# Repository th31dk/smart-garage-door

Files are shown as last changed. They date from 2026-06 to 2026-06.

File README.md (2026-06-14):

<h1 align="center">
    ESPGarageLink
</h1>
<h4 align="center">
    Inexpensive Garage Door Opener Link for Home Assistant
</h4>

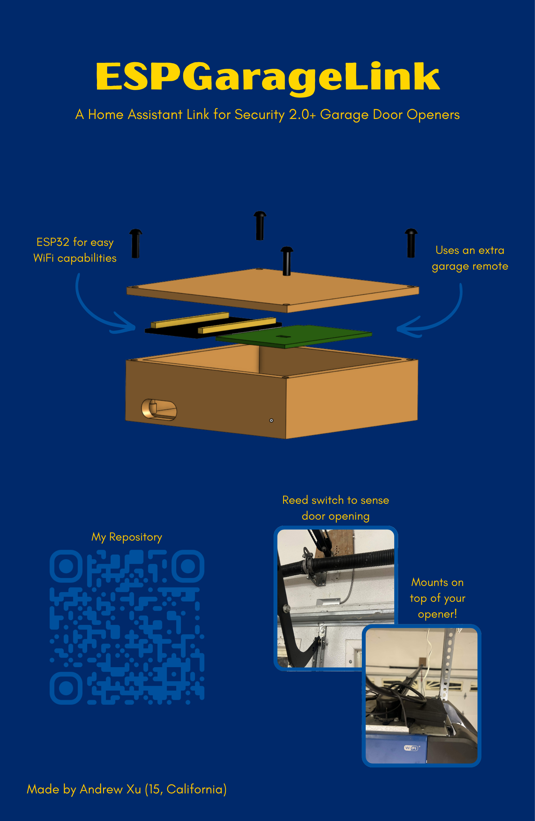
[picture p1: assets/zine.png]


<h2 align="center">
About This Project
</h2>
Throughout my life, I would often forget if I closed garage door was closed before heading out of the house. I would have to turn around for the slight chance that it was left open. I built this project to counter this. It uses ESPHome to easily integrate with Home Assistant.

<h2 align="center">
BOM
</h2>

|Part Number|Part Name |Quantity|Sourcing Link |Cost  |Notes |
|---|---|---|---|---|---|
|1 |ESP32 |1 |https://www.aliexpress.us/item/3256806060462387.html|$5.02 | |
|2 |Garage Door Remote|1 |https://a.co/d/0b3jvMXJ |$6.99 |has to be compatible with your garage opener model|
|3 |22awg dual wire |100ft |https://a.co/d/04LgN8tN |$15.99| |
|4 |Reed Switch |1 |https://a.co/d/087Lrm4S |$9.88 | |
|5 |M3x10 BHCS |4 |https://www.aliexpress.us/item/2251832624537980.html|$2.02 | |
|6 |1K Resistor |1 |https://www.aliexpress.us/item/3256802303553096.html|$0.90 | |
|7 |2N2222A Transistor|1 |https://www.aliexpress.us/item/3256808419495041.html|$1.91 | |

<h2 align="center">
Assembly
</h2>

|Case Assembly |Wiring Diagram |
|---|---|
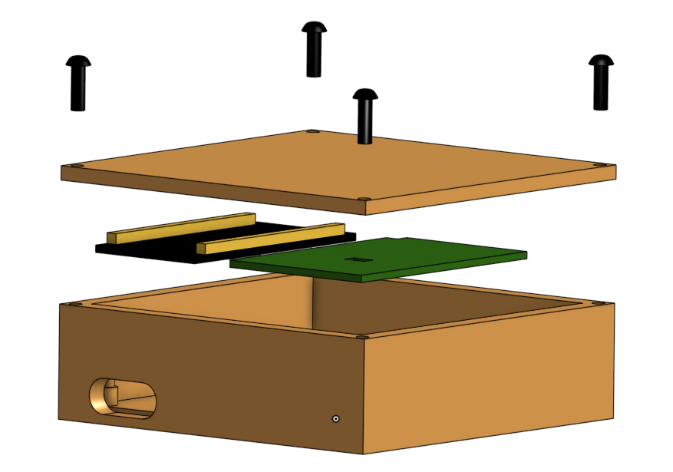
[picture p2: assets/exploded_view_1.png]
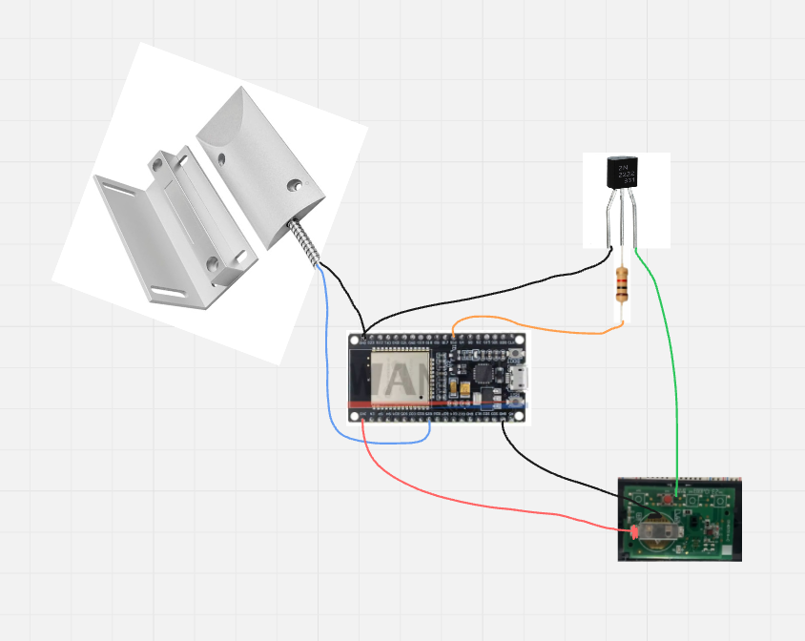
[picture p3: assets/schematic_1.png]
|||

1. Solder the wires to the correct spots on the Garage Remote PCB
2. Place the ESP32 and PCB inside the case.
4. Measure out the length of wire you need to connect the sensor to the ESP32 and cut it. (**MAKE SURE TO ADD SOME EXTRA LENGTH**)
5. String it through the circular hole in the case and connect it to the ESP32
6. Solder the rest of the connections
7. Screw the top case on
8. Flash your ESP32 with ESPHome
9. Link the ESP32 to ESPHome and upload the code to it. 
10. Install the parts in your garage

Source files can be found [here](https://cad.onshape.com/documents/4649b205c89024a5f1492af2/w/5978872a114fc81fb7337ada/e/29e5e7a7f49cdcf4b48956bb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)

<h2 align="center">
Credits
</h2>

Thank you to [Hack Club](https://hackclub.com/) for supporting my projects! They're truly an amazing organization.

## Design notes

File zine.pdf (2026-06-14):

# ESPGarageLink

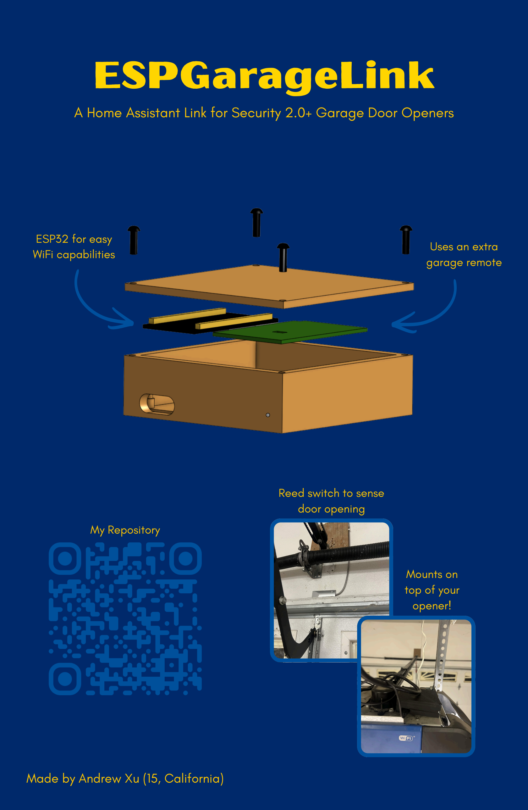
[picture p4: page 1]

### A Home Assistant Link for Security 2.0+ Garage Door Openers

Made by Andrew Xu (15, California)

ESP32 for easy
WiFi capabilities

Uses an extra
garage remote

Reed switch to sense
door opening

Mounts on
top of your
opener!

My Repository

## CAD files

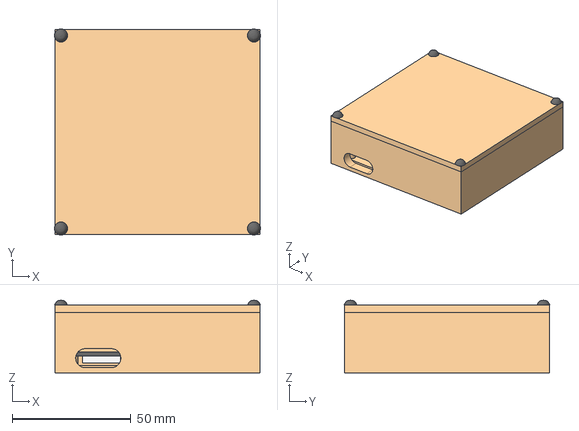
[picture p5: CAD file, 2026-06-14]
3D Models/Project Assembly.step
86.7 x 86.7 x 30.6 mm

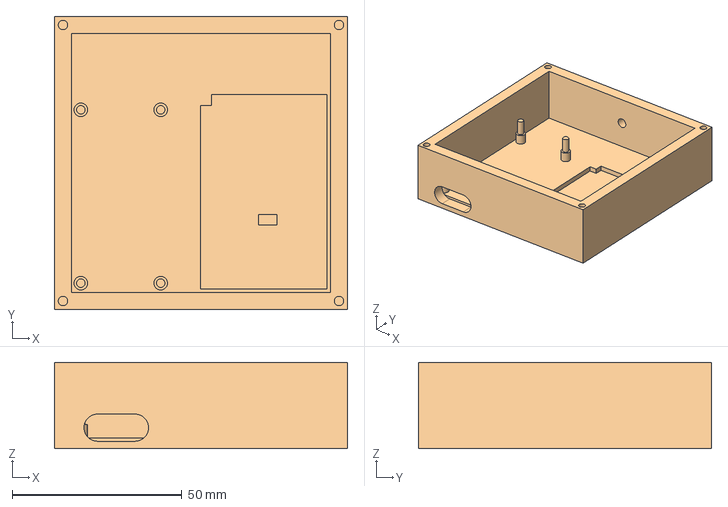
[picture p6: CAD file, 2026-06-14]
3D Models/Case Base.step
86.2 x 86.2 x 25.4 mm

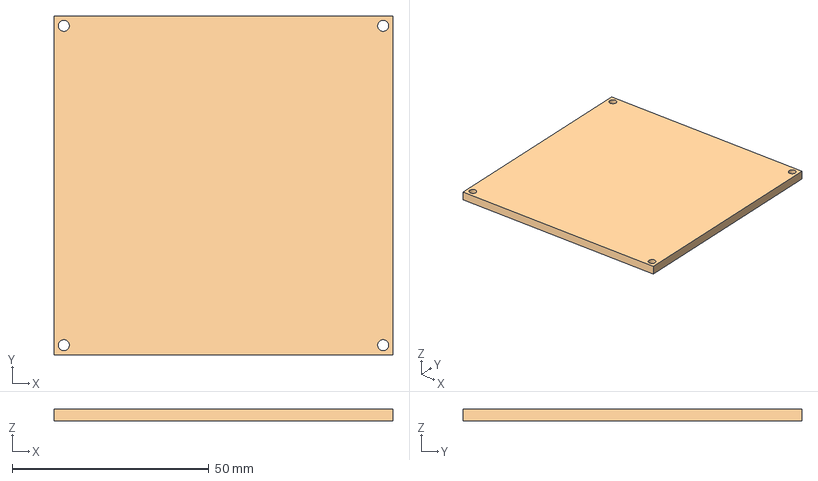
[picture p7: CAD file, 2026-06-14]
3D Models/Case Top.step
86.2 x 86.2 x 3.17 mm

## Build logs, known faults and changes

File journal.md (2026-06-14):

# Journal Information
Hi, my name is Andrew and welcome to my project journal! I will be documenting my entire journey right here. 

## Engineering Design Process
Throughout this project, I will be using the engineering design process to iterate on my designs. 

1. Identify the problem
2. Brainstorm Solutions
3. Implement The Best One
4. Build The Model
5. Test For Problems

# Journal Entries
## June 12th, 2026 - Friday
So, for the past year, I've wanted to smartify my house, but most products seemed overpriced and didn't fit my needs. I also didn't have an excuse to spend that much money on smart home products. Well, I realized I was getting to places late because my parents would forget whether or not they'd closed the garage door, and we'd have to go back home when we were already a mile away.

After some research, I've found that all the solutions didn't quite fit my constraints. The simplest solution I found was using myQ. My current garage door even has myQ built in. Now, don't get me wrong, myQ seems very simple to set up, except for the fact that they stopped supporting smart ecosystem software like Home Assistant and HomeKit. From that problem, RATDGO and Open Garage were born. They both essentially hack the garage door opener into letting Home Assistant use it. They're almost perfect, except it's kind of expensive to buy them. 

Now for my idea. I want to make a cheaper version that has all the features I need.

Here's what I want:

- Ability to open and close from my phone
- Ability to see if the door is open or closed

I know that doesn't seem like a lot of features, but we can always add more in v2.

Well the first feature I want to have is seeing if it's open or not. For this, I think we should take some inspiration from security systems. To secure the garage door, companies usually use a reed switch. A reed switch is a switch that switches when a magnet is near. My dad actually has a spare one, so I'll just use that one. 

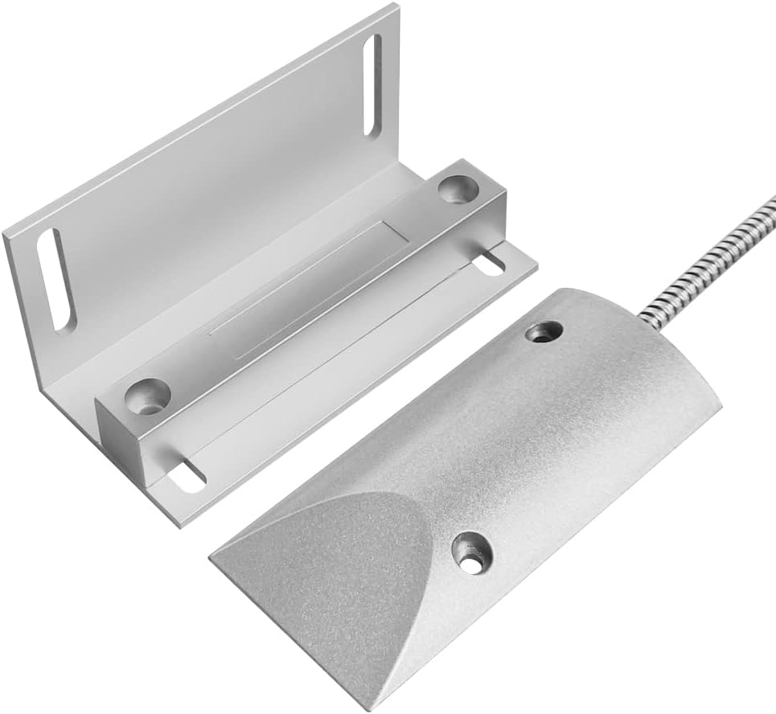
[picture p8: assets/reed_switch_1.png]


Before I continue, I want to test the reed switch first. I hooked up an LED to my power supply and put the reed switch in the middle. When the magnet got close, the LED turned on. When I removed the magnet, the L:ED turned off

|Magnet Near|Magnet Away|
|---|---|
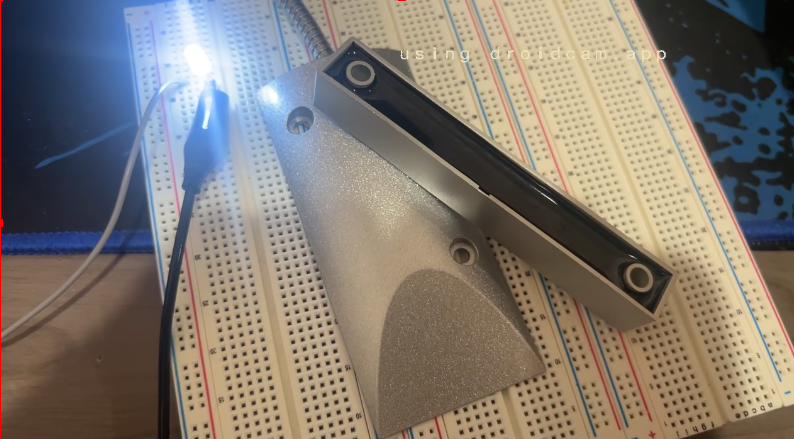
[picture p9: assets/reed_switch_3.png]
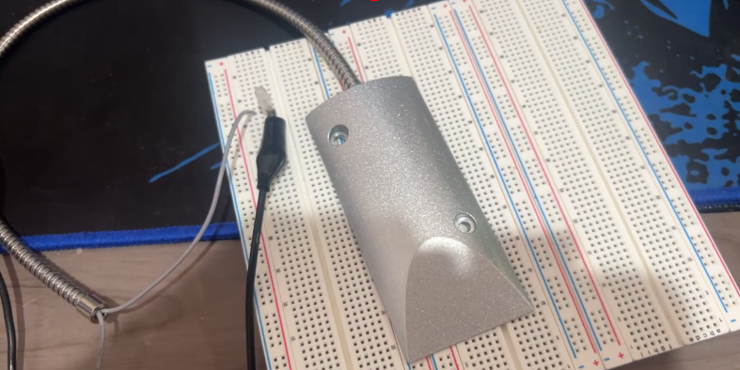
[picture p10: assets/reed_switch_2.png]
|||

Since we now have the first feature covered, lets move on to the next: remote control. At first, I wanted to place the esp32 right next to the wall mounted button and have a servo press the button, but that is not only too far but also would be an eyesore. For this reason, I decided to use the remotes that you place in your car. 

I wanted to break one open to see how it worked. I pried it open with a flathead screwdriver. 

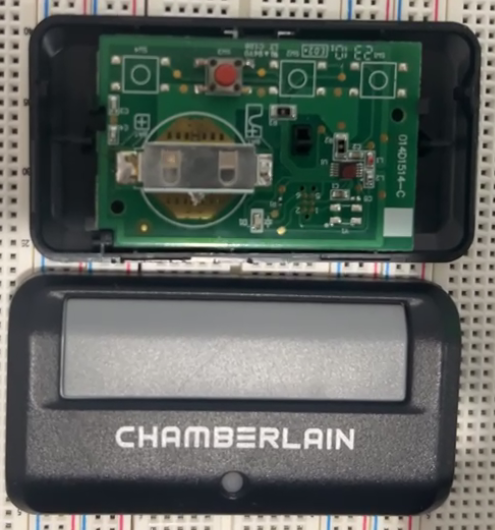
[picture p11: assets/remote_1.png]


Overall, it seems pretty simple. The remote is powered by 3V CR2032 battery. An IC then detects if the button shorts it to ground, then sends out an encrypted signal. Since I don't want to try and hack the encryption system, I'll just short the pins with a transistor. 

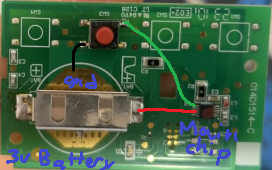
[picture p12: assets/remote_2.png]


Now, I want to wire and code a test for the remote. I'll tell the remote short the IC to ground for around 200ms through serial. If everything goes to plan, it should open my garage door. Also, it will tell me if the garage is closed or open according to if the sensor senses the magnet

To start, I soldered some jumpers to the remote

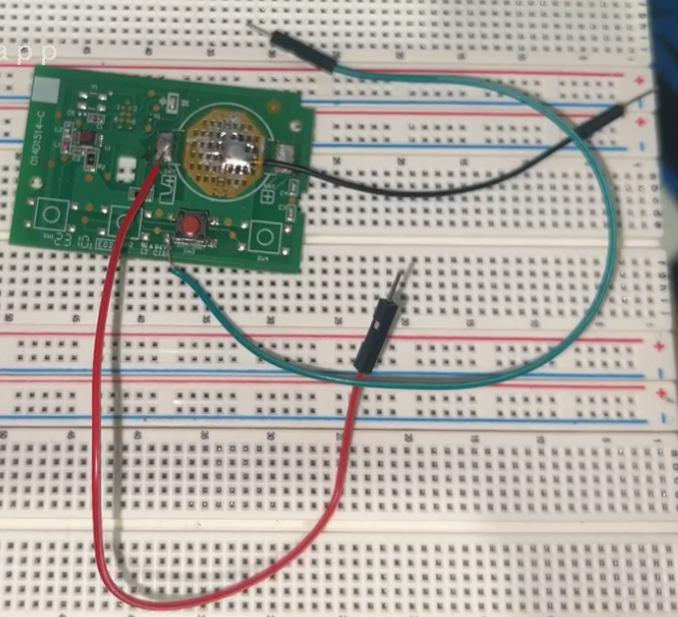
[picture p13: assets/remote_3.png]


I then wired it up to the breadboard with the esp32. I tested if the 3.3v pin from the ESP32 was enough to power it by clicking the button. It opened my garage door so it's a success.

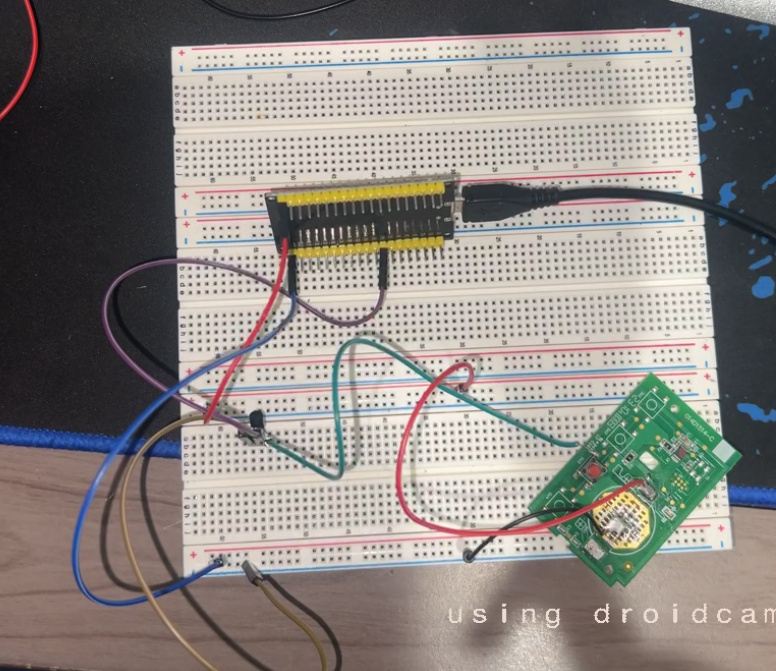
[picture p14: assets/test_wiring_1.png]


Next, let's write the code! This will be my first time configuring ESPHome so bear with me. 

I started off by flashing ESPHome onto my ESP32 board, and the auto config took like 30 minutes. After it was done, I looked at the [docs](https://esphome.io/guides/getting_started_hassio/) to see what to do next. 

The tutorial taught me how to program the ESP32 reed switch. It was fairly easy since it only required around 10 lines of code. 

Next, I'll program the ESP32 for the transistor circuit. 

At first, I tried programming the ESP32 with the button function, but using the switch function worked out much better. 

I thought my code was completely broken, but turns out I wired everything wrong, so I also rewired it. 

## June 13th, 2026 - Saturday
Since everything works now, I will move on to the enclosure. 

I want to mount it on top the garage door opener. Not only is there a power plug there, but the case won't be as much of an eyesore. 

My garage gets pretty hot in the summer, so I'll print it in PETG. 

My ESP32 board has 2.5mm mounting holes, but I don't own any 2.5mm bolts, so I decided to extrude pins that go through the middle of each hole to keep the ESP32 secure. 

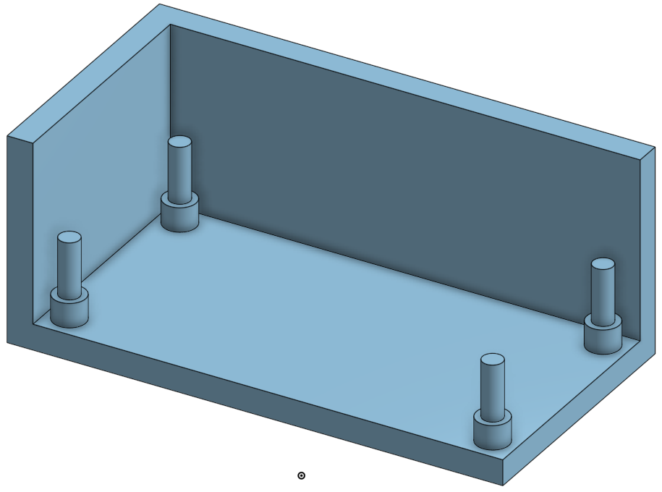
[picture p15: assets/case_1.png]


I only printed this corner piece because I wanted to test out if the ESP32 would fit. 

After printing it, the shorter axis fit perfectly, but the longer axis was a bit too short so the pins bent when I pressed the ESP32 in. I decided to reprint it with 2mm of extra distance. 



Now the pins are too far apart, I will shrink the distance by 1mm and reprint. I hope it'll actually fit now. 

It worked perfectly! Let's move on to designing the rest of this case. I put 2.8mm holes in the corners so I can attach a lid with M3 bolts. I didn't want the walls around the screw to be too thin either, so I made each wall 5mm instead of 3.175mm.

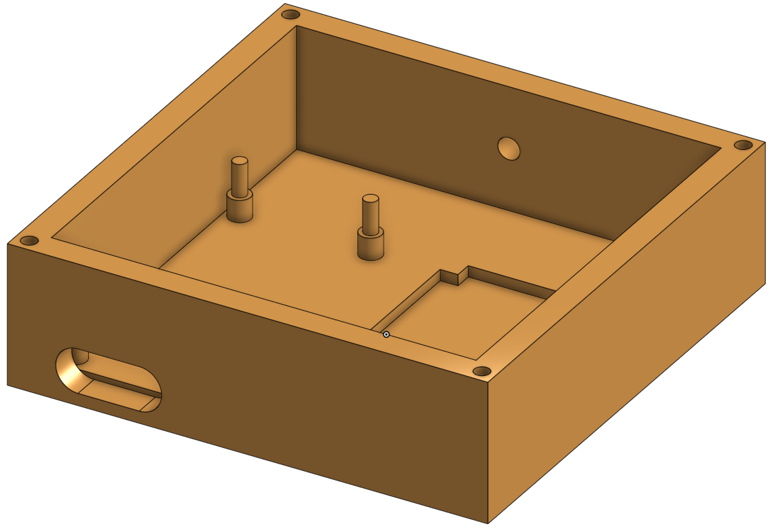
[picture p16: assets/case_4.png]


I then measured the dimensions of the PCB and drew it out. I added 0.2mm of clearance on each side so the PCB could fit easier. 

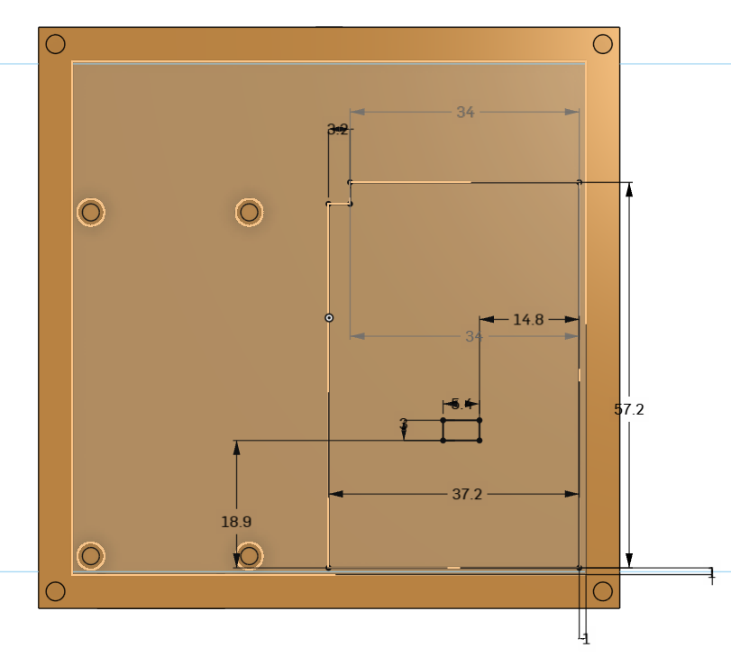
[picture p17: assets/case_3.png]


I sent the case to print.

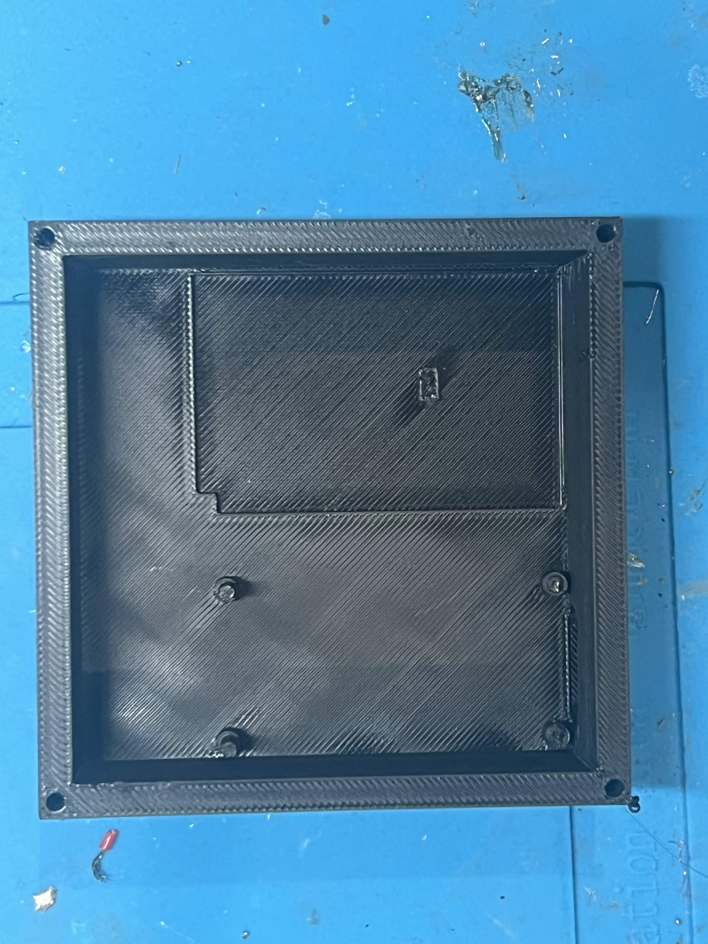
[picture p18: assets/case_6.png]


After the base case was done printing, I began soldering all the electronics together. The overall process was easy except some flux got into my eye. I used some heatshrink and some electrical tape to insulate the pins from the transistor and ground wires from touching each other

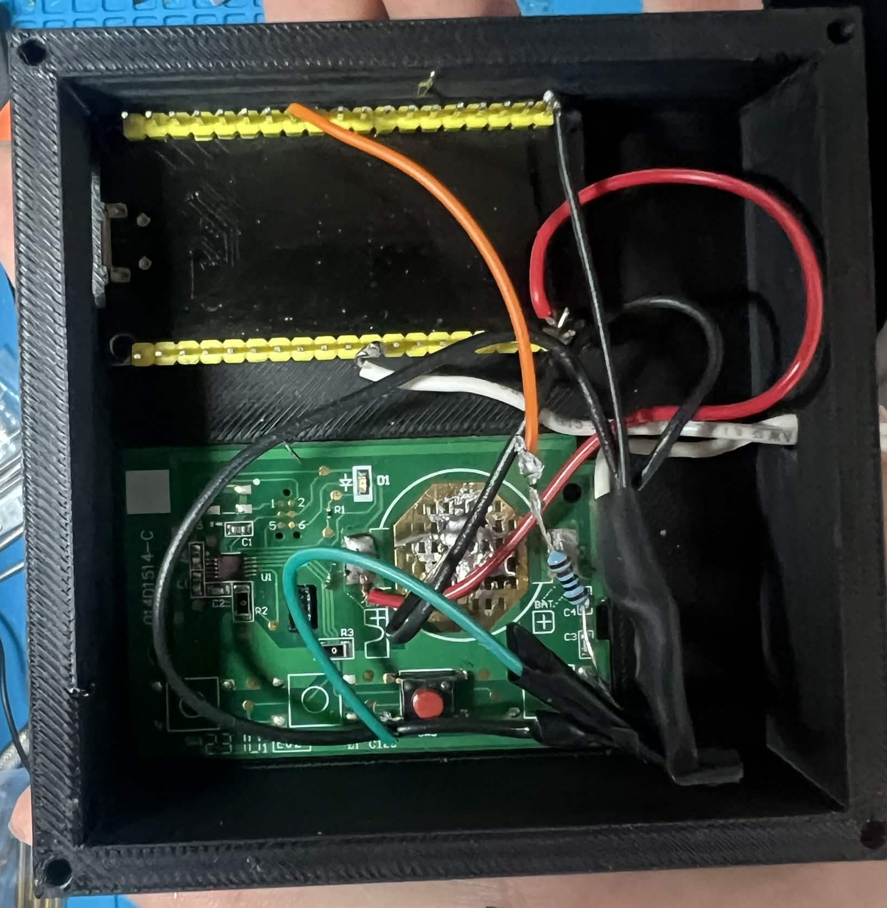
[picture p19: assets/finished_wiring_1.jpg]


After that, I decided to model the top of the case. I didn't really bother adding any design to it because it wouldn't be seen. I'm planning on placing it above the motor unit. Also, adding holes for design lets dust in which is kind of bad. 

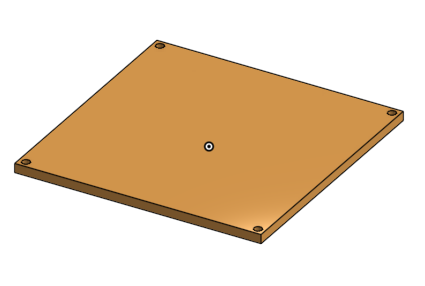
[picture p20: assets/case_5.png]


After that, I sent it to print. While it was printing, I wanted to do the assembly for the case. I modeled a rough model of the PCB and ESP32. 

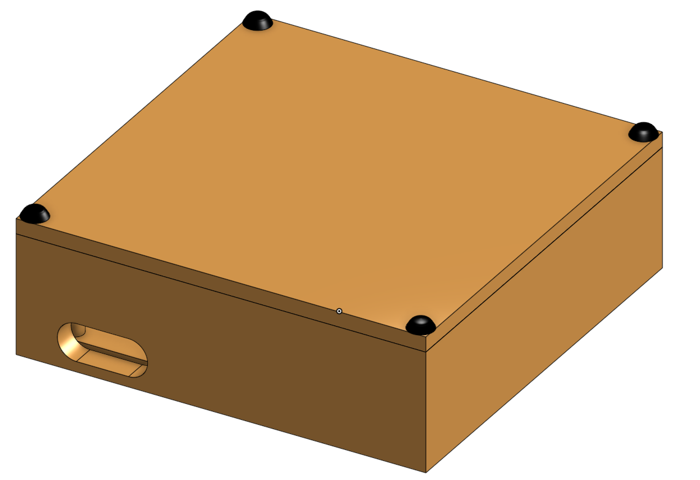
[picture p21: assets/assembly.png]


By the time I finished the assembly, the top was done. I attached the top to the bottom with 4 M3x10 bolts. 

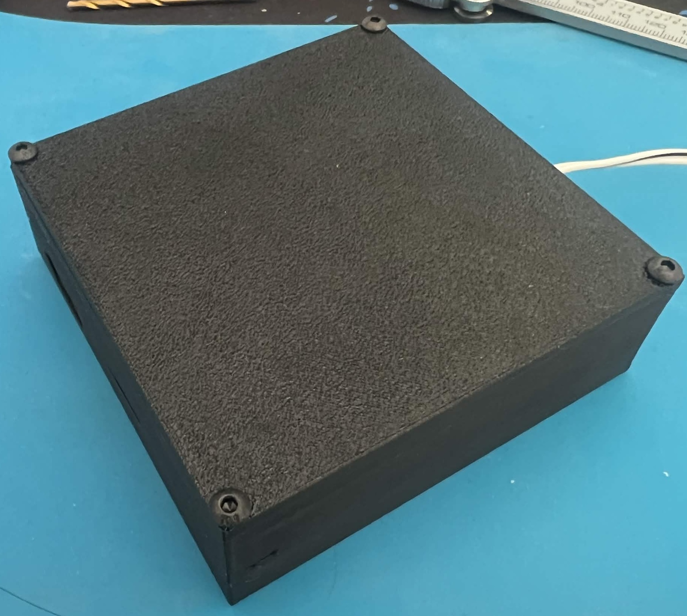
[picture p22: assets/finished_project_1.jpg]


Later, I installed the reed switch and the magnet. When the garage door is open, it pulls away the magnet, releasing the switch. 

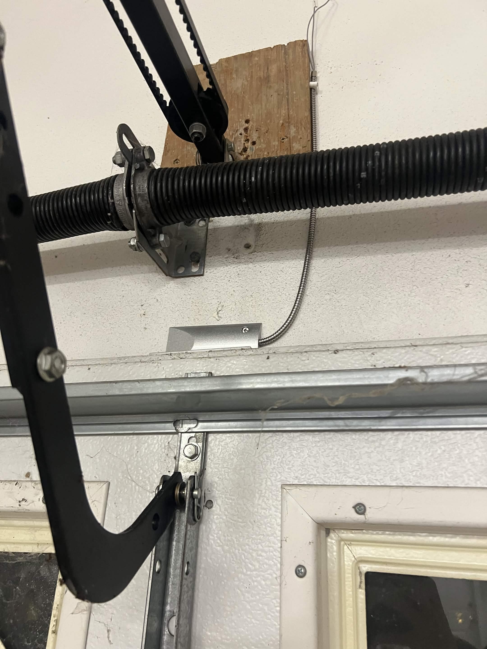
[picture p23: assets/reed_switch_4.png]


I then wired it to the main box that I put atop the motor.

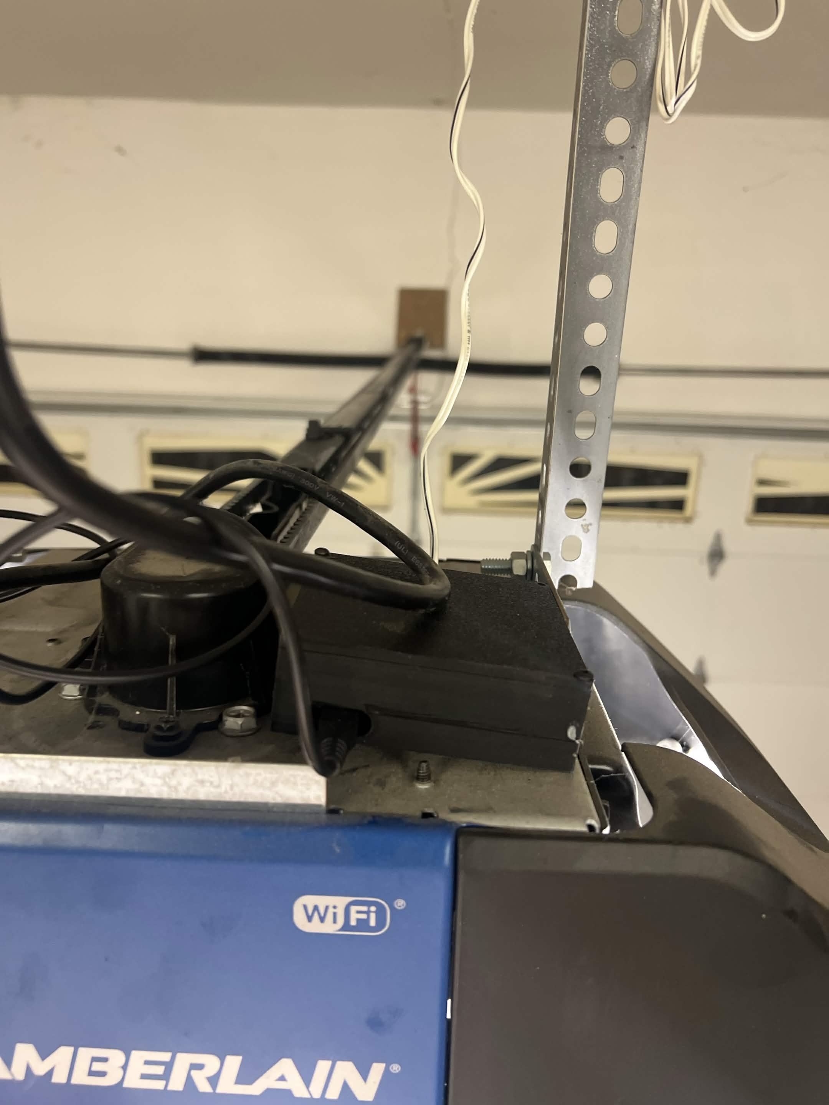
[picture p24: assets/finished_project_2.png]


## June 14th, 2026 - Sunday
Hey guys! It's submission day today, so I'll have to rush finishing the repository. To start, I'll make a checklist to see I've checked everything off. 

**README**
- [x] Project Description
- [x] Screenshots of Assembly
- [x] Wiring Diagram

**Design**
- [x] Original
- [x] Secure
- [x] Firmware
- [x] BOM in Repository
- [x] 3D Models in Repository
- [x] Zine PDF in Repository

**Zine**
- [x] A5
- [x] In README
- [x] Description
- [x] Central Graphic
- [x] QR Code
- [x] Name

I realized that I was missing a wiring diagram. At first I tried to do it in KiCAD, but I couldn't create a symbol for the garage remote, so I just went on a digital whiteboard and drew it there



Next, I was missing the 3D models, so I exported them from Onshape. I also attached the Onshape link in the README.

Now for the zine! I wanted to do a blue and yellow color template that I saw online

After some time, I think I whipped up a decent zine. 
